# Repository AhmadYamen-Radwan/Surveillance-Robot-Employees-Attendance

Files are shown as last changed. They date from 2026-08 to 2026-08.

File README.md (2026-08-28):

# Surveillance Robot — Employees Attendance

<div align="center">

**An Autonomous Mobile Robot System for Employee Attendance Tracking Using Real-Time Face Recognition**








</div>

---

## 📋 Table of Contents

- [Overview](#-overview)
- [Key Features](#-key-features)
- [System Architecture](#-system-architecture)
- [Technology Stack](#-technology-stack)
- [Hardware Components](#-hardware-components)
- [Software Modules](#-software-modules)
- [Robot Navigation & Control](#-robot-navigation--control)
- [Face Recognition Pipeline](#-face-recognition-pipeline)
- [Performance Results](#-performance-results)
- [Getting Started](#-getting-started)
- [Project Structure](#-project-structure)
- [Future Improvements](#-future-improvements)
- [Contributing](#-contributing)
- [License](#-license)
- [Contact](#-contact)

---

## 🎯 Overview

**Surveillance Robot — Employees Attendance** is a comprehensive autonomous mobile robot system designed to modernize workplace attendance tracking. The robot autonomously navigates through office environments, visits designated locations, performs real-time face recognition, and logs employee attendance with timestamps and location data. This system eliminates traditional attendance fraud, reduces administrative overhead, and provides accurate verification of employee presence at their actual workstations.

### Problem Addressed

Traditional attendance systems (manual signatures, ID cards, fingerprint scanners) suffer from:
- ❌ Physical contact requirements
- ❌ Vulnerability to fraud (buddy punching)
- ❌ Long queues at central checkpoints
- ❌ Inability to verify employee location within the workspace
- ❌ Lack of granularity for multi-department organizations

### Our Solution

An autonomous robot that:
- ✅ Physically verifies presence at the employee's workspace
- ✅ Uses contactless AI-powered face recognition
- ✅ Provides real-time attendance logging with location data
- ✅ Operates autonomously with minimal human intervention
- ✅ Reduces administrative overhead and human error

---

## ⚡ Key Features

### Robot Navigation
- **Fuzzy Logic Line Following**: Smooth, robust path tracking using fuzzy logic controllers
- **Stop Detection**: Magnetic marker detection for precise office stops
- **Obstacle Avoidance**: Ultrasonic sensor-based collision avoidance
- **Automatic Return**: Returns to base station after completing the tour

### Face Recognition
- **Real-Time Detection**: SSD-based face detection in video streams
- **Deep Learning Embeddings**: OpenFace 128-dimensional feature vectors
- **Accurate Matching**: Cosine similarity with dual-threshold confidence system
- **Employee Database**: JSON-based profile management with geometric median embedding

### User Interface
- **Live Video Stream**: Real-time monitoring with face overlays
- **Attendance Logs**: Timestamped records with employee names and confidence scores
- **Profile Management**: Easy employee registration and database updates
- **Admin Dashboard**: Comprehensive monitoring and control interface

---

## 🏗️ System Architecture

```mermaid
graph TB
    subgraph "Robot Platform"
        A[Arduino Uno] --> B[L298D Motor Driver]
        A --> C[IR Line Sensors x2]
        A --> D[HC-SR04 Ultrasonic]
        A --> E[Magnetic Stop Detector]
        B --> F[DC Motors x4]
    end
    
    subgraph "Vision Module"
        G[ESP32-CAM] --> H[OV2640 Camera]
        G --> I[Wi-Fi MJPEG Stream]
    end
    
    subgraph "PC Processing Unit"
        J[Python Application] --> K[Face Detection SSD]
        K --> L[Embedding Extraction OpenFace]
        L --> M[Database Matching]
        M --> N[Attendance Logging]
        O[Tkinter GUI] --> J
        P[Training App] --> Q[dataset.json]
    end
    
    I --> J
    A -- "Stop Signal" --> J
    E --> A
    C --> A
    D --> A
```

### Data Flow

1. **Robot Navigation**: Arduino reads sensors → Fuzzy logic computes motor speeds → Robot follows line
2. **Stop Detection**: Magnetic marker detected → Arduino sends "Stop" signal to PC
3. **Face Capture**: ESP32-CAM streams video → PC captures frame during 10-second dwell
4. **Face Processing**: SSD detects faces → OpenFace extracts embeddings → Matching against database
5. **Attendance Logging**: Recognized employees logged with timestamp and confidence → GUI updated

---

## 💻 Technology Stack

| Component | Technology | Purpose |
|---|---|---|
| **Robot Controller** | C++ (Arduino) | Motor control, sensor fusion, fuzzy logic navigation |
| **Vision Module** | C++ (ESP32) | Camera initialization, MJPEG streaming, Wi-Fi connectivity |
| **Recognition Engine** | Python 3.8+ | Face detection, embedding extraction, matching algorithm |
| **Deep Learning** | OpenCV, OpenFace (Torch) | SSD face detection, 128D embedding extraction |
| **User Interface** | Tkinter | Admin dashboard, live video, profile management |
| **Data Storage** | JSON | Employee database, attendance logs |
| **Communication** | HTTP/MJPEG, Serial | Video streaming, robot-PC communication |

---

## 🔧 Hardware Components

### Robot Platform (Arduino-Based)

| Component | Model/Type | Function |
|---|---|---|
| **Microcontroller** | Arduino Uno | Central control for motor and sensors |
| **Motor Driver** | L298D Shield | Drives 4 DC motors with PWM control |
| **DC Motors** | 4x 12V, 100 RPM | Differential drive wheel motion |
| **Line Sensors** | TCRT5000 (Analog) | Black line detection for path following |
| **Obstacle Sensor** | HC-SR04 (Ultrasonic) | Obstacle detection (≤ 20 cm range) |
| **Stop Detection** | Magnetic Sensor | Detects magnetic markers at office locations |
| **Power** | 2x 18650 Li-ion (7.4V) | Motor and Arduino power supply |

### Vision Module (ESP32-CAM)

| Component | Specification |
|---|---|
| **Module** | AI-Thinker ESP32-CAM |
| **Camera** | OV2640 (2MP) |
| **Resolution** | Up to 1600×1200 |
| **Stream Format** | MJPEG over HTTP |
| **Discovery** | mDNS (esp32cam.local) + UDP broadcast |
| **Power** | 5V DC (via FTDI/USB) |

### PC Processing Unit

- **OS**: Windows/Linux/macOS
- **Python**: 3.8 or later
- **Requirements**: Sufficient CPU/GPU for real-time deep learning inference
- **Storage**: Employee database (dataset.json), attendance logs (attendance.log)

---

## 📦 Software Modules

### Embedded Software

#### Arduino (`robot_code.cpp`)
- **Sensor Reading**: IR sensors, ultrasonic, magnetic detector
- **Fuzzy Logic Controller**: 9-rule inference system for line following
- **Motor Control**: PWM signal generation for differential steering
- **Stop Detection**: Office marker detection with 10-second dwell
- **Obstacle Avoidance**: Reactive collision handling
- **Return to Base**: Auto-return after completing tour

#### ESP32-CAM (`esp32_main.cpp`, `app_httpd.cpp`)
- **Wi-Fi Configuration**: Connection to pre-configured network
- **Camera Initialization**: OV2640 setup with JPEG compression
- **mDNS Discovery**: Hostname broadcast (esp32cam.local)
- **UDP Broadcast**: Periodic IP address and hostname announcement
- **MJPEG Server**: HTTP endpoint serving continuous video stream

### PC Application (Python)

#### Core Modules

| Module | File | Responsibility |
|---|---|---|
| **Face Recognition** | `embedding_engine.py` | SSD face detection, OpenFace embedding extraction |
| **Recognition Engine** | `recognition_engine.py` | Multi-threaded pipeline, matching, database management |
| **User Interface** | `interface.py` | Tkinter GUI, live video display, admin controls |
| **Training App** | `training_app.py` | Employee registration, embedding generation |
| **Configuration** | `engine_configuration.py` | System settings, config.yaml management |
| **Data Models** | `face_profile.py` | FaceProfile dataclass for structured face data |
| **Camera Utils** | `camera_config.py` | Save/load camera selection preferences |

---

## 🤖 Robot Navigation & Control

### Fuzzy Logic Line Following

The robot uses a fuzzy logic controller for smooth and robust line following, chosen over PID for its superior handling of non-linearities and sensor uncertainties.

#### Input Variables
- **Left IR Value**: Analog reading (0-1023) from left TCRT5000 sensor
- **Right IR Value**: Analog reading from right sensor

#### Fuzzification (Membership Functions)

| Linguistic Label | Left IR Range | Right IR Range | Region |
|---|---|---|---|
| **Black** | 0 – 250 | 0 – 250 | Line is dark |
| **Dark Grey** | 125 – 500 | 125 – 500 | Edge of line |
| **Transition** | 300 – 750 | 300 – 750 | Line boundary |
| **Background** | 500 – 1023 | 500 – 1023 | Floor is light |

#### Fuzzy Rules (9 Core Rules)

```mermaid
graph TD
    A[Left IR: Black<br>Right IR: Background] --> B[Sharp Right Turn]
    C[Left IR: Black<br>Right IR: Black] --> D[Straight]
    E[Left IR: Black<br>Right IR: Transition] --> F[Medium Right Turn]
    G[Left IR: Transition<br>Right IR: Background] --> H[Soft Right Turn]
    I[Left IR: Background<br>Right IR: Black] --> J[Sharp Left Turn]
```

#### Defuzzification & Motor Control

1. **Rule Activation**: Each rule produces a `μ` (degree of activation) value
2. **Speed Calculation**: 
   ```
   M1 = max(μ1*200, μ2*180, μ3*150, μ4*200, μ5*100, μ6*200, μ7*-150, μ8*-150, μ9*180, μ10*130)
   ```
3. **Normalization**:
   ```
   Max = max(|M1|, |M2|, |M3|, |M4|)
   Mi_norm = (Mi / Max) * 255
   ```
4. **Final Wheel Speeds**:
   ```
   LeftSpeed = (M1_norm + M4_norm) / 2
   RightSpeed = (M2_norm + M3_norm) / 2
   ```

### Stop Detection at Offices

- **Method**: Magnetic markers placed on the line at each office
- **Detection**: Dedicated magnetic sensor on robot
- **Action**: Motors stop → 10-second dwell time for face recognition
- **Resume**: After dwell time, robot continues to next office

### Obstacle Avoidance

1. **Detection**: HC-SR04 ultrasonic sensor (threshold: 20 cm)
2. **Emergency Stop**: Immediate halt
3. **Backward Movement**: Reverse for 400 ms
4. **Turn**: Rotate left/right for 500 ms
5. **Resume**: Reacquire line and continue

### Return to Base

- **State**: After last office visit, robot ignores magnetic markers
- **Action**: Continues following line to starting point
- **Stop**: Unique marker signals completion of tour

---

## 👤 Face Recognition Pipeline

### Overview

```mermaid
graph LR
    A[Video Stream] --> B[Face Detection SSD]
    B --> C[Crop Face]
    C --> D[Embedding Extraction OpenFace]
    D --> E[Cosine Similarity Matching]
    E --> F[Attendance Logging]
    D --> G[Database dataset.json]
    G --> E
```

### 1. Face Detection (SSD)

- **Model**: Caffe-based Single Shot Detector
- **Preprocessing**: Resize to 300×300, subtract mean RGB (104.0, 177.0, 123.0)
- **Confidence Threshold**: 0.5 for valid detections
- **Output**: Bounding boxes scaled back to original image dimensions

### 2. Face Embedding Extraction (OpenFace)

- **Model**: OpenFace (Torch-based, FaceNet architecture)
- **Preprocessing**: Resize to 96×96, normalize to [0, 1]
- **Output**: 128-dimensional L2-normalized unit vector
- **Training Data**: FaceScrub and CASIA-WebFace

### 3. Database Management

- **Storage**: JSON format (`dataset.json`)
- **Structure**: List of employee names + embeddings
- **Registration**: `training_app.py` utility
  - Select multiple images per employee
  - Compute geometric median of embeddings (robust to outliers)
  - L2-normalize final embedding
  - Append to database

### 4. Matching Algorithm

- **Metric**: Cosine similarity
- **Formula**: `Cosine_similarity = 1 - cosine_distance`

#### Thresholds

| Threshold | Value | Action |
|---|---|---|
| **Min_confidence** | 0.5 | Confident match → Green bounding box with name |
| **Unknown_avoid_threshold** | 0.35 | Potential match → Display with lower confidence |
| **Below 0.35** | - | Unknown → Save crop for review, list in "Unknown Profiles" |

### 5. Attendance Logging

**Process**:
1. Arduino sends "Stop" signal to PC
2. PC captures a single frame from video stream
3. Face recognition pipeline processes the frame
4. Logs recognized employees with:
   - Timestamp
   - Employee Name
   - Office Number
   - Confidence Score
   - Status ("PRESENT")
5. If no faces detected within 5 seconds: Logs "No employee present"
6. GUI updates in real-time
7. Robot resumes movement after dwell time

---

## 📊 Performance Results

### Face Recognition Accuracy

| Condition | Accuracy | Processing Time |
|---|---|---|
| **Normal Lighting** | 92% | 0.71 seconds/frame |
| **Low Light** | ~75% | 0.80 seconds/frame |
| **Backlit** | ~70% | 0.85 seconds/frame |

### Navigation Performance

| Metric | Result |
|---|---|
| **Line Following** | Smooth, within ±2 cm deviation |
| **Curve Handling** | Successful at 90° turns |
| **Stop Precision** | ±1 cm at magnetic markers |
| **Obstacle Avoidance** | 100% success at 20 cm threshold |
| **Route Completion** | 100% for predefined paths |

### System Performance

- **Video Latency**: ~200 ms (ESP32-CAM MJPEG stream)
- **Recognition Pipeline**: 0.71 seconds per frame
- **Database Lookup**: < 50 ms for 50 employees
- **GUI Refresh Rate**: 30 fps

---

## 🚀 Getting Started

### Prerequisites

| Requirement | Specification |
|---|---|
| **Python** | 3.8 or higher |
| **Arduino IDE** | 1.8.x or higher |
| **ESP32 Board Support** | ESP32 package in Arduino IDE |
| **PC** | Modern CPU (quad-core recommended) |
| **Operating System** | Windows/Linux/macOS |
| **Camera** | USB or built-in (for testing) |

### Hardware Assembly

1. **Robot Chassis**:
   - Assemble 4-wheel differential drive chassis
   - Mount Arduino Uno with L298D shield
   - Install TCRT5000 sensors at front (straddling line)
   - Mount HC-SR04 ultrasonic sensor at front
   - Install magnetic sensor underneath

2. **ESP32-CAM Setup**:
   - Connect OV2640 camera to ESP32-CAM
   - Flash with provided firmware
   - Configure Wi-Fi credentials
   - Verify stream at `http://esp32cam.local/stream`

3. **Power System**:
   - Connect 18650 batteries (7.4V) to motor driver
   - Power Arduino via USB or battery
   - Power ESP32-CAM via 5V FTDI/USB

### Software Installation

#### 1. Clone the Repository
```bash
git clone https://github.com/AhmadYamen-Radwan/Surveillance-Robot-Employees-Attendance.git
cd Surveillance-Robot-Employees-Attendance
```

#### 2. Create Python Virtual Environment
```bash
python3 -m venv venv
source venv/bin/activate  # Linux/macOS
# or
venv\Scripts\activate     # Windows
```

#### 3. Install Python Dependencies
```bash
pip install -r requirements.txt
```

#### 4. Arduino Setup
- Open `robot_code.cpp` in Arduino IDE
- Install required libraries (if any)
- Upload to Arduino Uno

#### 5. ESP32-CAM Setup
- Open `esp32_main.cpp` in Arduino IDE
- Configure Wi-Fi SSID and password
- Upload to ESP32-CAM
- Wait for LED to indicate Wi-Fi connection

#### 6. Configure System
Edit `config.yaml`:
```yaml
camera:
  source: http://esp32cam.local/stream  # or local camera: 0
  width: 640
  height: 480

recognition:
  model: models/openface.t7
  min_confidence: 0.5
  unknown_avoid_threshold: 0.35

robot:
  offices: 5
  dwell_time: 10  # seconds
  stop_marker: magnetic
```

### Running the System

#### Start the Recognition Engine
```bash
python backend/app.py
```

#### Start the GUI
```bash
python interface.py
```

#### Register Employees
```bash
python training_app.py
```

#### Robot Controller (on robot)
```bash
python robot/controller.py --config config.yaml
```

## 🔮 Future Improvements

### Advanced Navigation
| Improvement | Description |
|---|---|
| **SLAM Implementation** | Replace line following with simultaneous localization and mapping |
| **ROS Integration** | Use Robot Operating System for advanced control |
| **Lidar/Depth Cameras** | Intel RealSense or similar for 3D mapping |
| **Dynamic Route Planning** | Adaptive path planning based on office layout |

### Enhanced Face Recognition
| Improvement | Description |
|---|---|
| **Low-Light Performance** | ESP32-CAM LED flashlight, IR cameras |
| **Liveness Detection** | Eye blinking, head movement checks to prevent photo fraud |
| **Model Fine-Tuning** | Transfer learning on employee dataset |
| **Multi-Face Processing** | Simultaneous recognition of multiple employees |

### System Scalability
| Improvement | Description |
|---|---|
| **Multi-Robot Integration** | Multiple robots communicating with central server |
| **REST API** | Integration with HR and payroll systems |
| **Cloud Deployment** | Centralized logging and management |
| **Role-Based Access** | Admin, manager, employee dashboards |

### Hardware Upgrades
| Improvement | Description |
|---|---|
| **Single Board Computer** | Raspberry Pi 4/5 for onboard processing |
| **Onboard AI Inference** | Edge TPU, NVIDIA Jetson for accelerated inference |
| **Intelligent Power Management** | Self-charging docking station |
| **24/7 Autonomous Operation** | Return to base, recharge, continue |

---

## 🤝 Contributing

We welcome contributions! Please follow these steps:

1. **Fork the repository**
2. **Create a feature branch**
   ```bash
   git checkout -b feat/your-feature-name
   ```
3. **Commit your changes**
   ```bash
   git commit -m "Add your feature description"
   ```
4. **Push to the branch**
   ```bash
   git push origin feat/your-feature-name
   ```
5. **Open a Pull Request**

### Contribution Guidelines
- Follow existing code style and conventions
- Add tests for new functionality
- Update documentation (README, comments, docstrings)
- Include hardware specifications for any hardware changes
- Provide clear description of changes in PR

---

## 📄 License

This project is licensed under the **MIT License**. See the [LICENSE](LICENSE) file for details.

---

## 📞 Contact

**Author:** Ahmad Yamen AbdulKader Radwan  




---

<div align="center">

**Surveillance Robot — Employees Attendance**  
*An Autonomous Mobile Robot for Modern Workforce Management*




*2026*

</div>

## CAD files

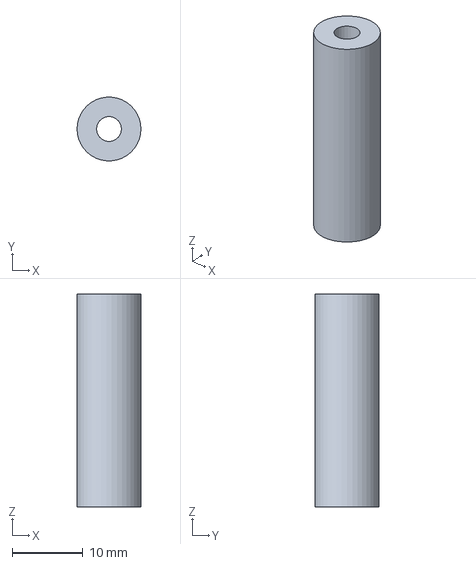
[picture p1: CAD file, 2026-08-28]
3D/shaft-Body.3mf
9.00 x 8.97 x 30.0 mm

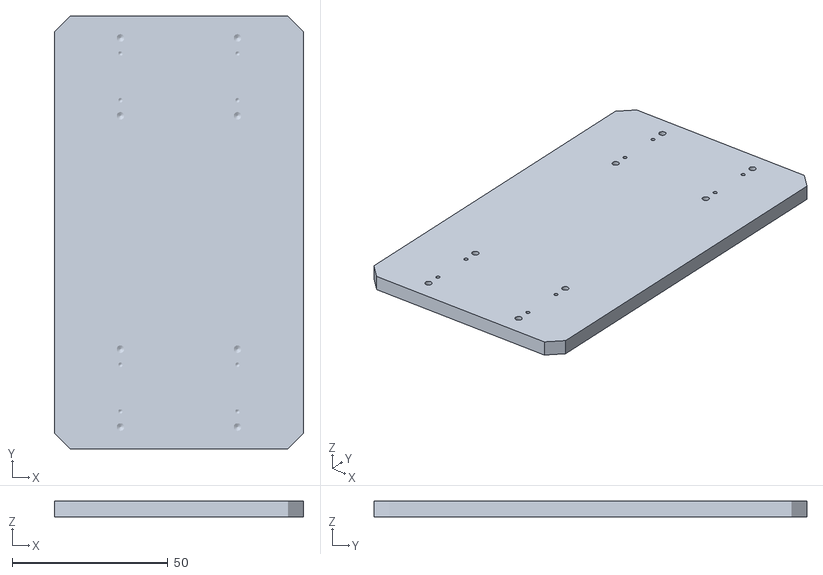
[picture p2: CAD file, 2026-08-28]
3D/to_print/base-Body.stl
80.0 x 139.0 x 5.00

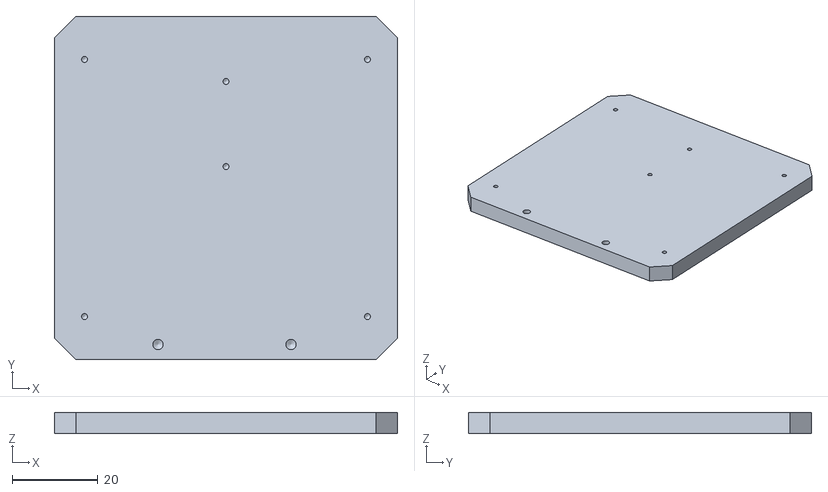
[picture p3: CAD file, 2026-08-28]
3D/to_print/top-Body.stl
80.0 x 80.0 x 5.00

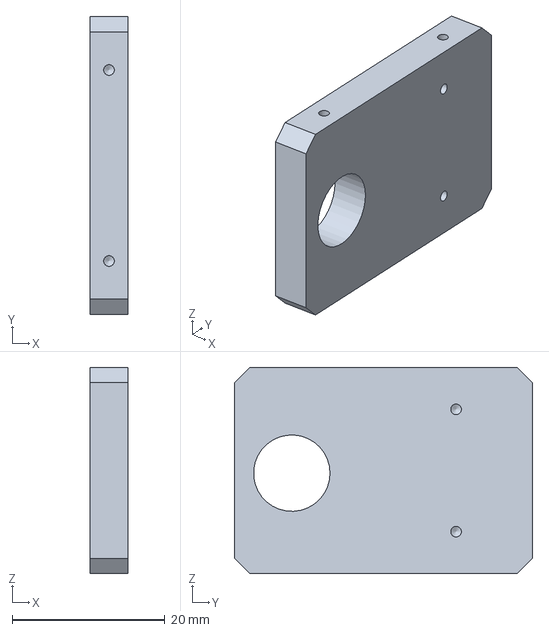
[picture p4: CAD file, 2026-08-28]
3D/gear-Body.3mf
5.00 x 39.0 x 27.0 mm

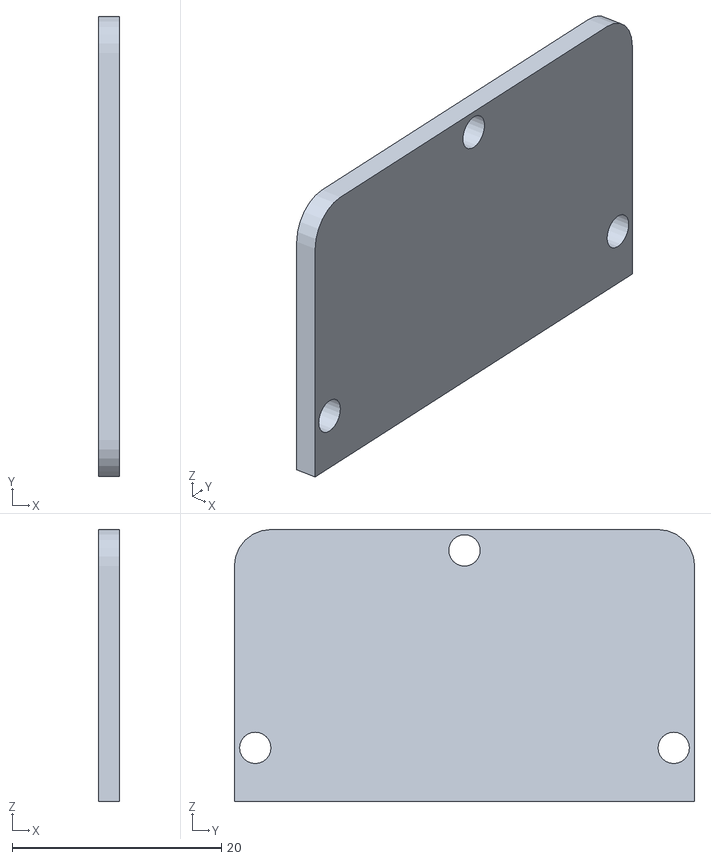
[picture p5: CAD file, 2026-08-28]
3D/to_print/Esp 32 spate 2x18650.stl
2.00 x 44.0 x 26.0

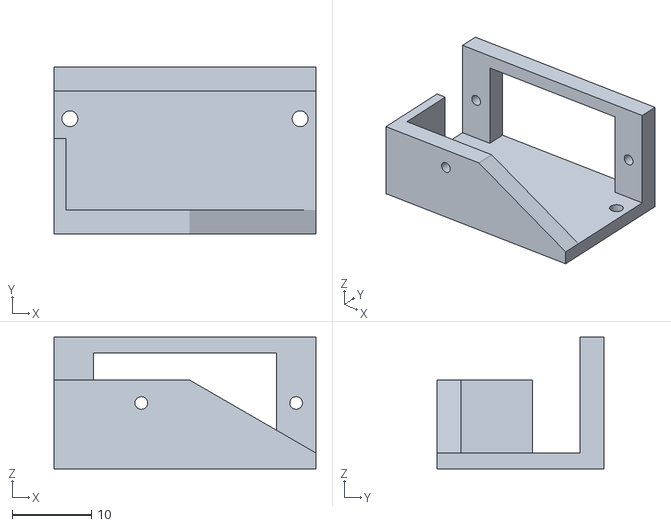
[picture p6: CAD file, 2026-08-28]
3D/to_print/Pan tilt top 2x18650.stl
33.0 x 21.0 x 16.6

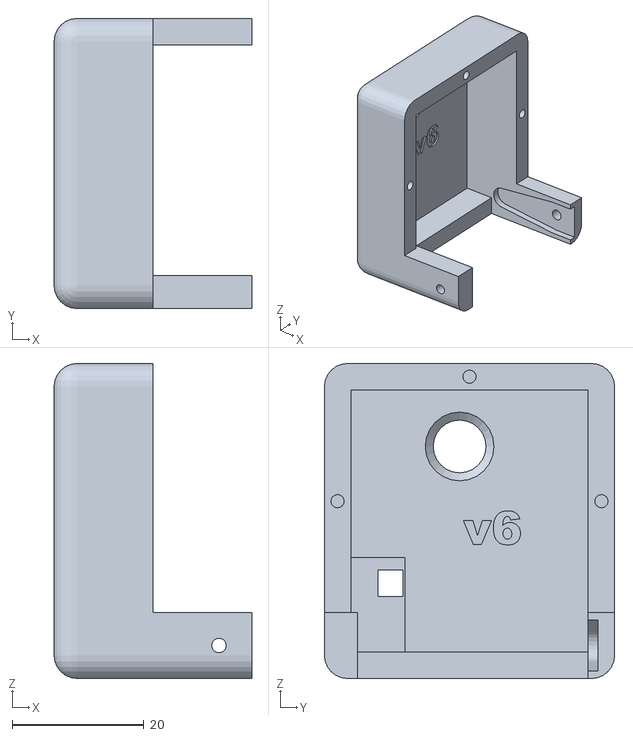
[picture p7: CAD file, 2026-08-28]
3D/to_print/Esp 32 corp 2x18650.stl
30.0 x 44.0 x 47.8

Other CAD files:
3D/middle-Body.3mf
3D/to_print/gear-Body.stl
3D/base.FCStd
3D/base-Body.3mf
3D/to_print/middle-Body.stl
3D/to_print/shaft-Body.stl
3D/top.FCStd
3D/middle.FCStd
3D/esp.FCStd
3D/top-Body.3mf

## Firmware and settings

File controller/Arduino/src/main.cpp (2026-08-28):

#include <Arduino.h>
#include <AFMotor.h>

#define BASE_SPEED 200
#define TURN_SPEED 150
#define SEARCH_SPEED 150
#define THRESHOLD 500
#define YELLOW_MIN 20
#define YELLOW_MAX 29

// Fuzzy controller membership ranges
#define BLACK_LOW 0
#define BLACK_HIGH 250
#define DARK_GREY_LOW 125
#define DARK_GREY_HIGH 500
#define TRANSITION_LOW 300
#define TRANSITION_HIGH 750
#define BACKGROUND_LOW 750
#define BACKGROUND_HIGH 1023

AF_DCMotor motor1(1);
AF_DCMotor motor2(2);
AF_DCMotor motor3(3);
AF_DCMotor motor4(4);

byte ir_right = A5;
byte ir_left = A4;

int left_speed = 0;
int right_speed = 0;
int state = 0;

// Startup pause variables
bool is_startup_paused = false;
unsigned long startup_pause_start = 0;
const unsigned long startup_pause_duration = 10000; // 10 seconds pause at startup

// Marker detection variables
bool marker_detected = false;
bool is_marker_paused = false;
unsigned long marker_pause_start = 0;
const unsigned long marker_pause_duration = 10000; // 10 seconds pause when office marker detected
int yellow_detection_count = 0;

// Office markers detected (2 offices, then base)
int office_marker_count = 0;
const int TOTAL_OFFICE_MARKERS = 2;
bool is_base_reached = false;
bool robot_finished = false;

// Cooldown to prevent re-detecting same marker
bool marker_cooldown = false;
unsigned long cooldown_start = 0;
const unsigned long cooldown_duration = 2000; // 2 seconds cooldown after pause

// Delay before pause after detection
bool delay_before_pause = false;
unsigned long detection_time = 0;
const unsigned long delay_duration = 500; // 0.5 seconds delay before pausing

// Fuzzy membership function results
float left_black = 0, left_dark_grey = 0, left_transition = 0, left_background = 0;
float right_black = 0, right_dark_grey = 0, right_transition = 0, right_background = 0;

// Fuzzy output speeds (initialized)
float m1_speed = 0, m2_speed = 0, m3_speed = 0, m4_speed = 0;

void controller(int, int);
void drive_all_motors(int, int);
void fuzzy_membership(int value, float &black, float &dark_grey, float &transition, float &background);
void fuzzy_inference(float l_black, float l_dark, float l_trans, float l_bg,
                     float r_black, float r_dark, float r_trans, float r_bg,
                     float &out1, float &out2, float &out3, float &out4);
void fuzzy_defuzzify(float out1, float out2, float out3, float out4, int &left_speed, int &right_speed);

// Fuzzy membership function for sensor values
void fuzzy_membership(int value, float &black, float &dark_grey, float &transition, float &background)
{
    // Black membership (0-250, peak at 0)
    if (value <= 0) black = 1.0;
    else if (value < 250) black = 1.0 - (value / 250.0);
    else black = 0.0;
    
    // Dark grey membership (125-500, center at 312.5)
    if (value <= 125) dark_grey = 0.0;
    else if (value < 312.5) dark_grey = (value - 125) / 187.5;
    else if (value < 500) dark_grey = 1.0 - ((value - 312.5) / 187.5);
    else dark_grey = 0.0;
    
    // Transition membership (300-750, center at 525)
    if (value <= 300) transition = 0.0;
    else if (value < 525) transition = (value - 300) / 225.0;
    else if (value < 750) transition = 1.0 - ((value - 525) / 225.0);
    else transition = 0.0;
    
    // Background membership (750-1023, peak at 1023)
    if (value <= 750) background = 0.0;
    else if (value < 886.5) background = (value - 750) / 136.5;
    else background = 1.0;
}

// Fuzzy inference engine
void fuzzy_inference(float l_black, float l_dark, float l_trans, float l_bg,
                     float r_black, float r_dark, float r_trans, float r_bg,
                     float &out1, float &out2, float &out3, float &out4)
{
    // Rule 1: Both sensors on blackm, Then go straight
    float rule1 = min(l_black, r_black);
    out1 = max(out1, rule1 * 200);  // motor1 forward
    out2 = max(out2, rule1 * 200);  // motor2 forward
    out3 = max(out3, rule1 * 200);  // motor3 forward
    out4 = max(out4, rule1 * 200);  // motor4 forward
    
    // Rule 2: Left black, right dark grey, Then slight right turn
    float rule2 = min(l_black, r_dark);
    out1 = max(out1, rule2 * 180);  // motor1 forward
    out2 = max(out2, rule2 * 150);  // motor2 forward (slower)
    out3 = max(out3, rule2 * 150);  // motor3 forward (slower)
    out4 = max(out4, rule2 * 180);  // motor4 forward
    
    // Rule 3: Left dark grey, right black, Then slight left turn
    float rule3 = min(l_dark, r_black);
    out1 = max(out1, rule3 * 150);  // motor1 forward (slower)
    out2 = max(out2, rule3 * 180);  // motor2 forward
    out3 = max(out3, rule3 * 180);  // motor3 forward
    out4 = max(out4, rule3 * 150);  // motor4 forward (slower)
    
    // Rule 4: Left black, right transition, Then medium right turn
    float rule4 = min(l_black, r_trans);
    out1 = max(out1, rule4 * 200);   // motor1 forward
    out2 = max(out2, rule4 * 100);   // motor2 forward (slow)
    out3 = max(out3, rule4 * 100);   // motor3 forward (slow)
    out4 = max(out4, rule4 * 200);   // motor4 forward
    
    // Rule 5: Left transition, right black, Then medium left turn
    float rule5 = min(l_trans, r_black);
    out1 = max(out1, rule5 * 100);   // motor1 forward (slow)
    out2 = max(out2, rule5 * 200);   // motor2 forward
    out3 = max(out3, rule5 * 200);   // motor3 forward
    out4 = max(out4, rule5 * 100);   // motor4 forward (slow)
    
    // Rule 6: Left black, right background, Then sharp right turn
    float rule6 = min(l_black, r_bg);
    out1 = max(out1, rule6 * 200);   // motor1 forward
    out2 = max(out2, rule6 * -150);  // motor2 backward
    out3 = max(out3, rule6 * -150);  // motor3 backward
    out4 = max(out4, rule6 * 200);   // motor4 forward
    
    // Rule 7: Left background, right black, Then sharp left turn
    float rule7 = min(l_bg, r_black);
    out1 = max(out1, rule7 * -150);  // motor1 backward
    out2 = max(out2, rule7 * 200);   // motor2 forward
    out3 = max(out3, rule7 * 200);   // motor3 forward
    out4 = max(out4, rule7 * -150);  // motor4 backward
    
    // Rule 8: Both sensors on transition or background, Then rotate/search
    float rule8 = max(min(l_trans, r_trans), min(l_bg, r_bg));
    out1 = max(out1, rule8 * -150);  // motor1 backward (rotate)
    out2 = max(out2, rule8 * 150);   // motor2 forward
    out3 = max(out3, rule8 * 150);   // motor3 forward
    out4 = max(out4, rule8 * -150);  // motor4 backward (rotate)
    
    // Rule 9: Left dark grey, right transition, Then gentle right turn
    float rule9 = min(l_dark, r_trans);
    out1 = max(out1, rule9 * 180);   // motor1 forward
    out2 = max(out2, rule9 * 130);   // motor2 forward
    out3 = max(out3, rule9 * 130);   // motor3 forward
    out4 = max(out4, rule9 * 180);   // motor4 forward
    
    // Rule 10: Left transition, right dark grey, Then gentle left turn
    float rule10 = min(l_trans, r_dark);
    out1 = max(out1, rule10 * 130);  // motor1 forward
    out2 = max(out2, rule10 * 180);  // motor2 forward
    out3 = max(out3, rule10 * 180);  // motor3 forward
    out4 = max(out4, rule10 * 130);  // motor4 forward
}

// Defuzzification using centroid method
void fuzzy_defuzzify(float out1, float out2, float out3, float out4, int &left_speed, int &right_speed)
{
    // Sum of all output memberships
    float sum1 = abs(out1);
    float sum2 = abs(out2);
    float sum3 = abs(out3);
    float sum4 = abs(out4);
    
    // If all outputs are zero, search mode
    if (sum1 < 0.01 && sum2 < 0.01 && sum3 < 0.01 && sum4 < 0.01) {
        left_speed = -SEARCH_SPEED;
        right_speed = SEARCH_SPEED;
        return;
    }
    
    // Normalize and scale to motor speed range
    float max_sum = max(max(sum1, sum2), max(sum3, sum4));
    if (max_sum > 0) {
        out1 = (out1 / max_sum) * 255;
        out2 = (out2 / max_sum) * 255;
        out3 = (out3 / max_sum) * 255;
        out4 = (out4 / max_sum) * 255;
    }
    
    // For differential drive, combine motor pairs
    // Left side: motors 1 and 4
    left_speed = constrain((out1 + out4) / 2, -255, 255);
    // Right side: motors 2 and 3
    right_speed = constrain((out2 + out3) / 2, -255, 255);
}

void controller(int sensor1, int sensor2)
{
    // Reset fuzzy outputs
    float out1 = 0, out2 = 0, out3 = 0, out4 = 0;
    
    // Calculate membership values for left sensor
    fuzzy_membership(sensor1, left_black, left_dark_grey, left_transition, left_background);
    
    // Calculate membership values for right sensor
    fuzzy_membership(sensor2, right_black, right_dark_grey, right_transition, right_background);
    
    // Perform fuzzy inference
    fuzzy_inference(left_black, left_dark_grey, left_transition, left_background,
                    right_black, right_dark_grey, right_transition, right_background,
                    out1, out2, out3, out4);
    
    // Defuzzify to get motor speeds
    fuzzy_defuzzify(out1, out2, out3, out4, left_speed, right_speed);
    
    // Update state for debugging
    if (left_speed > 50 && right_speed > 50) state = 1;
    else if (left_speed > right_speed) state = 2;
    else if (right_speed > left_speed) state = 3;
    else state = 4;
}

void setup()
{
    // Stop all motors on startup
    motor1.run(RELEASE);
    motor2.run(RELEASE);
    motor3.run(RELEASE);
    motor4.run(RELEASE);
    
    motor1.setSpeed(0);
    motor2.setSpeed(0);
    motor3.setSpeed(0);
    motor4.setSpeed(0);
    
    pinMode(A5, INPUT);
    pinMode(A4, INPUT);
    
    motor1.setSpeed(255);
    motor2.setSpeed(255);
    motor3.setSpeed(255);
    motor4.setSpeed(255);
    
    // Start the 10-second startup pause
    is_startup_paused = true;
    startup_pause_start = millis();
}

void loop()
{
    // Check if robot is in startup pause
    if (is_startup_paused)
    {
        // Keep motors stopped
        drive_all_motors(0, 0);
        
        // Check if 10-second startup pause is over
        if (millis() - startup_pause_start >= startup_pause_duration)
        {
            is_startup_paused = false;
        }
        
        delay(100);
        return;
    }
    
    // Check if robot has finished (base reached)
    if (robot_finished)
    {
        // Keep motors stopped forever
        drive_all_motors(0, 0);
        delay(100);
        return;
    }
    
    int left_val = analogRead(ir_left);
    int right_val = analogRead(ir_right);
    
    // Check if robot is paused due to office marker detection
    if (is_marker_paused)
    {
        // Keep motors stopped
        drive_all_motors(0, 0);
        
        // Check if 10-second marker pause is over
        if (millis() - marker_pause_start >= marker_pause_duration)
        {
            is_marker_paused = false;
            marker_detected = false;
            yellow_detection_count = 0;
            
            // Start cooldown to prevent re-detecting same marker
            marker_cooldown = true;
            cooldown_start = millis();
        }
        
        delay(100);
        return;
    }
    
    // Check if in cooldown period (prevents re-detecting same marker)
    if (marker_cooldown)
    {
        if (millis() - cooldown_start >= cooldown_duration)
        {
            marker_cooldown = false; // Cooldown finished
        }
        else
        {
            // During cooldown, just follow the line normally
            controller(left_val, right_val);
            drive_all_motors(left_speed, right_speed);
            delay(10);
            return;
        }
    }
    
    // Check if in delay-before-pause period
    if (delay_before_pause)
    {
        // Continue following line during delay
        controller(left_val, right_val);
        drive_all_motors(left_speed, right_speed);
        
        // Check if 0.5 seconds has passed
        if (millis() - detection_time >= delay_duration)
        {
            delay_before_pause = false;
            
            // Now pause the robot
            marker_detected = true;
            is_marker_paused = true;
            marker_pause_start = millis();
            
            // Stop motors immediately
            drive_all_motors(0, 0);
            yellow_detection_count = 0;
            
            delay(50);
            return;
        }
        
        delay(10);
        return;
    }
    
    // YELLOW MARKER DETECTION
    if (!marker_detected && !marker_cooldown && !delay_before_pause)
    {
        bool left_yellow = (left_val >= YELLOW_MIN && left_val <= YELLOW_MAX);
        bool right_yellow = (right_val >= YELLOW_MIN && right_val <= YELLOW_MAX);
        
        if (left_yellow || right_yellow)
        {
            yellow_detection_count++;
            
            // Need 2 consecutive detections to confirm
            if (yellow_detection_count >= 2)
            {
                // Increment office marker count
                office_marker_count++;
                
                // Check if this is the base marker (3rd marker)
                if (office_marker_count > TOTAL_OFFICE_MARKERS)
                {
                    // BASE REACHED, Stop forever
                    is_base_reached = true;
                    robot_finished = true;
                    drive_all_motors(0, 0);
                    yellow_detection_count = 0;
                    delay(50);
                    return;
                }
                else
                {
                    // Office marker detected, start 0.5 second delay before pausing
                    delay_before_pause = true;
                    detection_time = millis();
                    yellow_detection_count = 0;
                    
                    delay(50);
                    return;
                }
            }
        }
        else
        {
            yellow_detection_count = 0;
        }
    }
    
    // Normal line following with fuzzy logic
    controller(left_val, right_val);
    drive_all_motors(left_speed, right_speed);
    
    delay(10);
}

void drive_all_motors(int left, int right)
{
    left = constrain(left, -255, 255);
    right = constrain(right, -255, 255);
    
    if (left > 0)
    {
        motor1.setSpeed(left);
        motor4.setSpeed(left);
        motor1.run(FORWARD);
        motor4.run(BACKWARD);
    }
    else if (left < 0)
    {
        motor1.setSpeed(-left);
        motor4.setSpeed(-left);
        motor1.run(BACKWARD);
        motor4.run(FORWARD);
    }   
    else
    {
        motor1.run(RELEASE);
        motor4.run(RELEASE);
    }
    
    if (right > 0)
    {
        motor2.setSpeed(right);
        motor3.setSpeed(right);
        motor2.run(BACKWARD);
        motor3.run(FORWARD);
    }
    else if (right < 0)
    {
        motor2.setSpeed(-right);
        motor3.setSpeed(-right);
        motor2.run(FORWARD);
        motor3.run(BACKWARD);
    }   
    else
    {
        motor2.run(RELEASE);
        motor3.run(RELEASE);
    }
}

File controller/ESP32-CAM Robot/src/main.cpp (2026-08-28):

#include "esp_camera.h"
#include <WiFi.h>
#include <WebSocketsServer.h>
#include <ESPmDNS.h>
#include <WiFiUdp.h>

// ========== Wi-Fi ==========
const char* ssid = "DeathKingdom";
const char* password = "20035112";

// ========== Camera Pins ==========
#define PWDN_GPIO_NUM     32
#define RESET_GPIO_NUM    -1
#define XCLK_GPIO_NUM      0
#define SIOD_GPIO_NUM     26
#define SIOC_GPIO_NUM     27
#define Y9_GPIO_NUM       35
#define Y8_GPIO_NUM       34
#define Y7_GPIO_NUM       39
#define Y6_GPIO_NUM       36
#define Y5_GPIO_NUM       21
#define Y4_GPIO_NUM       19
#define Y3_GPIO_NUM       18
#define Y2_GPIO_NUM        5
#define VSYNC_GPIO_NUM    25
#define HREF_GPIO_NUM     23
#define PCLK_GPIO_NUM     22

// ========== Server & WebSocket ==========
WiFiServer server(80);
WebSocketsServer webSocket = WebSocketsServer(81);
WiFiUDP udp;

// ========== State ==========
bool ledState = false;
bool flashState = false;
bool mirrorState = false;
bool robotRunning = false;
String deviceName = "esp32cam";
unsigned long lastBroadcast = 0;
unsigned long lastFrame = 0;
int fpsCount = 0;
unsigned long lastFpsPrint = 0;

// ========== HTML with WebSocket ==========
const char index_html[] PROGMEM = R"rawliteral(
<!DOCTYPE html>
<html>
<head>
    <meta name="viewport" content="width=device-width, initial-scale=1">
    <title>ESP32-CAM</title>
    <style>
        * { margin: 0; padding: 0; box-sizing: border-box; }
        body {
            font-family: Arial, sans-serif;
            background: #0a0a0a;
            color: #fff;
            display: flex;
            justify-content: center;
            align-items: center;
            min-height: 100vh;
            padding: 10px;
        }
        .container {
            max-width: 900px;
            width: 100%;
            background: #1a1a2e;
            border-radius: 20px;
            padding: 20px;
            text-align: center;
            box-shadow: 0 10px 40px rgba(0,0,0,0.8);
        }
        h1 {
            font-size: 28px;
            background: linear-gradient(135deg, #e94560, #0f3460);
            -webkit-background-clip: text;
            -webkit-text-fill-color: transparent;
        }
        .subtitle { color: #666; font-size: 14px; margin-bottom: 15px; }
        .video-container {
            background: #000;
            border-radius: 10px;
            overflow: hidden;
            margin: 15px 0;
            aspect-ratio: 4/3;
            display: flex;
            align-items: center;
            justify-content: center;
            position: relative;
        }
        canvas {
            width: 100%;
            height: 100%;
            display: block;
        }
        .fps-overlay {
            position: absolute;
            top: 10px;
            right: 10px;
            background: rgba(0,0,0,0.7);
            padding: 4px 12px;
            border-radius: 12px;
            font-size: 14px;
            color: #4caf50;
            font-weight: bold;
        }
        .controls {
            display: flex;
            flex-wrap: wrap;
            gap: 10px;
            justify-content: center;
            margin: 15px 0;
        }
        .btn {
            padding: 12px 25px;
            border: none;
            border-radius: 25px;
            font-size: 14px;
            font-weight: bold;
            cursor: pointer;
            transition: 0.3s;
            color: #fff;
            min-width: 100px;
        }
        .btn:hover { transform: scale(1.05); }
        .btn-capture { background: #e94560; }
        .btn-led { background: #0f3460; }
        .btn-led.on { background: #f9a825; color: #000; }
        .btn-flash { background: #f57c00; }
        .btn-mirror { background: #2e7d32; }
        .btn-robot { background: #6a1b9a; }
        .btn-robot.on { background: #4caf50; }
        .info { color: #666; font-size: 12px; margin-top: 10px; }
        .fps { color: #4caf50; font-weight: bold; }
        .status {
            display: inline-block;
            padding: 2px 10px;
            border-radius: 10px;
            font-size: 11px;
        }
        .status-online { background: #2e7d32; color: #fff; }
        .status-offline { background: #c62828; color: #fff; }
        @media (max-width: 600px) {
            .btn { padding: 10px 15px; font-size: 12px; min-width: 70px; }
        }
    </style>
</head>
<body>
    <div class="container">
        <h1>ESP32-CAM</h1>
        <div class="subtitle">WebSocket Streaming</div>
        
        <div class="video-container">
            <canvas id="canvas"></canvas>
            <div class="fps-overlay" id="fpsDisplay">0 FPS</div>
        </div>
        
        <div class="controls">
            <button class="btn btn-capture" onclick="capturePhoto()">Capture</button>
            <button class="btn btn-led" id="ledBtn" onclick="toggleLED()">LED</button>
            <button class="btn btn-flash" id="flashBtn" onclick="toggleFlash()">Flash</button>
            <button class="btn btn-mirror" id="mirrorBtn" onclick="toggleMirror()">Mirror</button>
            <button class="btn btn-robot" id="robotBtn" onclick="toggleRobot()">Robot</button>
        </div>
        
        <div class="info">
            FPS: <span class="fps" id="fps">0</span> | 
            Status: <span id="status" class="status status-online">● Online</span> |
            IP: <span id="ip">loading...</span>
        </div>
    </div>
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

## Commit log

2026-08-28 New Commit
    [Esp 32 corp 2x18650.stl, Esp 32 spate 2x18650.stl, Pan tilt top 2x18650.stl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]
2026-08-28 Add README.md — Surveillance Robot — Employees Attendance

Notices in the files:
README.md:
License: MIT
